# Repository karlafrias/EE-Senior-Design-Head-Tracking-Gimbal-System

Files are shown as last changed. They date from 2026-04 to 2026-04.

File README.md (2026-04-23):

# Head-Tracking FPV Camera Control System

University of North Texas  
College of Engineering  
Department of Electrical Engineering  
Senior Design  
April 2026  

## Team Members
- Karla McKenzie
- Jacob Shillingburg
- Martins Ugoh

## Advisor
- Dr. Namuduri

## Link to Youtube:
https://www.youtube.com/watch?v=_BPLgMK_N9A

This repository contains code, PCB files, 3D models, pin diagrams, datasheets, presentation materials, and documentation for our senior design project

## Repository Contents

**3D Models:** Contains 3D CAD models for the head-tracking system and related mechanical components created in Fusion 360. Also includes files used for 3D printing and system integration.

**Code:** Contains the embedded code used for the head-tracking FPV camera control system, including communication and control logic for the headset and camera system.

**Datasheets:** Contains manufacturer datasheets for key project components used in the system design and integration.

**PCB Files:** Contains the PCB design files created in Altium, along with fabrication outputs, gerber files, and other board-related design documents.

**Pin Diagrams:** Contains wiring references, pin mappings, and connection diagrams for the major components used in the project.

**Poster-Slides:** Contains our senior design poster, presentation slides, and supporting materials used to present the project.

**Technical Report:** Contains the written technical report and supporting documentation for the project.

## Project Abstract

Inspired by Max Imagination and redesigning his board, our senior design project focuses on developing a custom head-tracking FPV camera control system for real-time remote viewing applications. The goal of this project is to create a more refined and functional board that supports directional camera control through natural head movement. By redesigning the board, the team aimed to improve organization, functionality, and overall integration while supporting future use in applications such as drones, remote sensing, and first responder assistance.

Our project involved designing the PCB in Altium, developing 3D CAD models in Fusion 360, selecting and sourcing components, assembling and soldering the board, testing power and signal behavior, and integrating the board with the camera and headset system. Along the way, the team addressed engineering challenges such as axis inversion, signal routing, communication reliability, mechanical fit, and hardware integration.

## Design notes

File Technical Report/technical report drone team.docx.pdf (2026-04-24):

# Design and Integration of a Head Tracking System for Remote Camera/Gimbal Control on a UAV Drone

# EENG 4990.001 Senior Design II

# Department of Electrical Engineering

# University of North Texas

# Denton, TX, USA

# Karla McKenzie

# Martins Ugoh

# Jacob Shillingburg

04/24/2026

Page | ii
Karla McKenzie, Jacob Shilingburg, Martins Ugoh April 2026

ACKNOWLEDGMENTS

We would like to thank the College of Engineering at the University of North Texas for funding our project. We also gratefully acknowledge Dr. Namuduri and the Autonomous Systems Laboratory for their mentorship, guidance, and technical insight throughout the development process. In addition, we thank the Department of Electrical Engineering for providing advice, resources, and access to equipment and materials that made this work possible.

KEYWORDS

- camera integration
- embedded systems
- gimbal control
- head tracking
- PCB design
- remote sensing
- wearable electronics

Page | iii

CONTENTS

Abstract | 3
Introduction | 4
Solution | 6
Design | 8

Implementation 14

Conclusion | 33
Future Work | 34
References | 35
Appendix | 36

Page | iv

THIS PAGE LEFT BLANK INTENTIONALLY

Page | 5

## Abstract

The project focused on developing a dedicated hardware platform capable of receiving head -tracking input, processing motion data, and transmitting control signals to the camera gimbal for pan and tilt movement. Electrical design considerations included signal routing, power distribution, filtering components, and connector integration, while mechanical design addressed mounting, alignment, and overall system fit. Prototype development and ground-based testing were completed to evaluate communication performance and system functionality. Results showed that the system successfully demonstrated head-tracking control and reliable wireless operation at distances of up to approximately 1 km under ground test conditions. Although full flight testing was not completed, the final prototype established a strong foundation for future integration into UAV-based remote sensing platforms. This work demonstrates the feasibility of a custom head-tracking control board and supports future improvements in stabilization, durability, and full aerial deployment.

Page | 6

## Introduction

Head tracking systems are widely used in robotics, drones, teleoperation, virtual reality, and assistive systems because they provide a more natural and immersive method of control. Instead of relying entirely on joysticks or manual directional input, these systems convert the user’s head movement into corresponding control signals. This allows the operator to direct a camera or gimbal system more intuitively and efficiently.

The goal of this project was to design and integrate a head tracking system capable of supporting a remote camera or gimbal platform. The system was intended to provide real-time directional control through head movement while returning a live video feed to the user through a headset. Achieving this required reliable electronics design, stable power regulation, practical PCB layout, and careful integration with both the camera and headset hardware.

Because the system is intended for a compact and mobile environment, the design had to emphasize low power consumption, hardware reliability, compact form factor, and ease of integration. This paper discusses the design process, implementation, testing, results, and future improvements of the head tracking system.

Page | 7

## Problem Statement

Traditional remote camera control methods can be difficult to use when the operator must divide attention between navigation, observation, and directional adjustment. This is especially true in drone or remote vision applications where fast response and natural user interaction are important. A head tracking system improves usability by allowing the camera orientation to follow the operator’s head motion.

However, implementing such a system introduces several engineering challenges. The system must provide stable power delivery, reliable communication, appropriate signal conditioning, and compact physical integration. It must also account for real-world issues such as control inversion, mounting constraints, and hardware debugging. The challenge of this project was therefore to develop a PCB-based hardware platform that could support these functions while remaining compact, reliable, and suitable for integration into a headset-camera system.

## Objectives

The objectives of this project were to:

1. design a PCB for the head tracking system using Altium;
2. select and source components required for sensing, regulation, and communication;
3. develop a complete bill of materials for fabrication and assembly;
4. assemble and solder the PCB for functional verification;
5. validate power and signal behavior using laboratory test equipment;
6. integrate the board with the camera and headset system;
7. support real-time transmission and directional control capability;
8. correct control issues related to axis inversion; and
9. prepare the design for final system-level implementation.

Page | 8

## Solution

Our solution is to use a custom PCB-based head-tracking gimbal system to control an FPV camera in real time. The system allows the camera to follow the natural head movements of the user, creating a more responsive and immersive remote viewing experience. The PCB serves as the main control platform and connects the microcontroller, wireless communication modules, power components, filtering capacitors, connectors, and servo motor outputs needed for operation. The system is powered by a lithium battery pack, allowing portable use and easier integration into a mobile platform. Head-tracking input is processed and transmitted wirelessly to the receiving side, where the servo motors drive the camera in pan and tilt directions. The system also includes custom mechanical components to support the camera and gimbal assembly while keeping the design compact and adaptable. Overall, the prototype functions as a head-tracking control system for remote sensing applications and demonstrated successful operation during ground testing, with wireless performance reaching distances of up to about 1 km. Although full flight testing was not completed, the design provides a strong foundation for future improvements in stabilization, integration, and expanded field use.

Page | 9

## System Overview

The head tracking system was designed as an embedded control platform that converts user head motion into directional commands for a remote camera gimbal assembly. The system is composed of a sensing stage, a processing stage, a wireless communication stage, regulated power distribution, and a remote actuation stage. These subsystems operate together to provide real-time camera positioning and visual feedback for remote sensing applications.

The main controller used in the system is the Pro Mini ATmega328P 5V/16 MHz microcontroller, which serves as the central processing unit on the custom PCB. This microcontroller receives motion data from the inertial sensor, processes the orientation-related input, and generates the control data required for transmission to the remote platform. Its small size, low power requirements, and compatibility with the rest of the embedded design made it suitable for integration into the head-mounted control hardware.

Head motion is measured using the MPU6050 gyroscope and accelerometer sensor, which provides motion and orientation data to the microcontroller. The MPU6050 combines a 3-axis gyroscope and a 3-axis accelerometer in a single device, allowing the system to detect changes in head position and angular movement. This sensor data is used to determine the operator’s motion and convert it into corresponding control signals for the remote camera system. The sensor communicates with the microcontroller through a digital interface and forms the primary input stage of the head tracking system.

Wireless transmission between the head-mounted unit and the remote camera platform is supported through an nRF24L01 transceiver module. This communication link allows processed motion data from the headset side to be sent to the receiving side of the system, where the camera or gimbal can respond accordingly. The wireless link is intended to support low-latency transfer of directional commands, which is important for natural and responsive camera movement.

The PCB also includes the required power regulation and filtering circuitry to support stable operation of the embedded components. Decoupling and bulk capacitors were included to reduce noise and maintain voltage stability for the microcontroller, sensor, and communication module. Proper power distribution was necessary to reduce electrical instability that could affect sensing accuracy, wireless transmission, or general system reliability.

On the receiver side, control signals are used to drive the gimbal mechanism so that its motion follows the user’s head movement. This creates a closed operator feedback loop in which head orientation is measured by the MPU6050, processed by the ATmega328P, transmitted wirelessly through the nRF24L01, and then used to reposition the remote camera. A live digital camera feed is returned to the headset, allowing the operator to immediately observe the resulting view direction.

Overall, the system integrates embedded sensing, onboard signal processing, wireless communication, and remote actuation into a compact hardware platform. This architecture supports intuitive camera control for drone-based remote sensing and first responder applications.

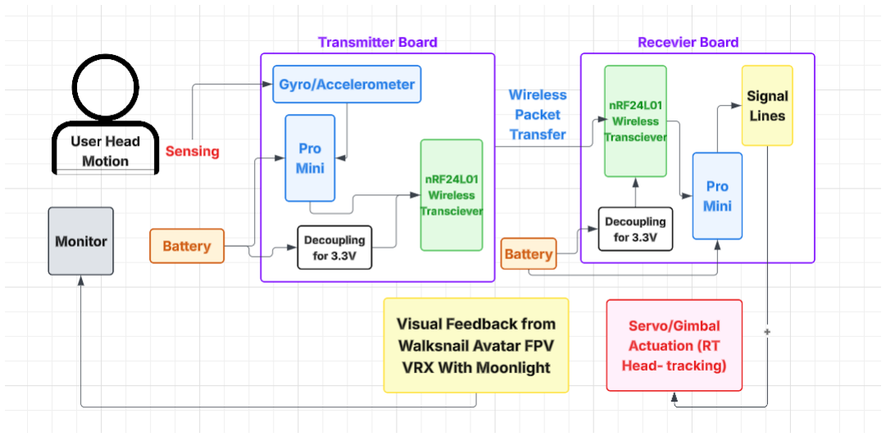
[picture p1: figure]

Page | 10

## Design

## Design Overview

Figure 1: PCB Carrier Board Overview Block Diagram

System-level block diagram of the head tracking platform showing the user input, transmitter board, wireless packet-based communication link, receiver board, and visual feedback path. On the transmitter side, head motion is measured by the gyro/accelerometer and processed by the Pro Mini before being sent through the nRF24L01 wireless transceiver. The receiver board accepts the transmitted packets and outputs the control signals used for servo or gimbal actuation. The diagram also shows the battery-powered supply and decoupling required for stable 3.3 V operation, as well as the returned visual feedback from the FPV system to the user monitor.

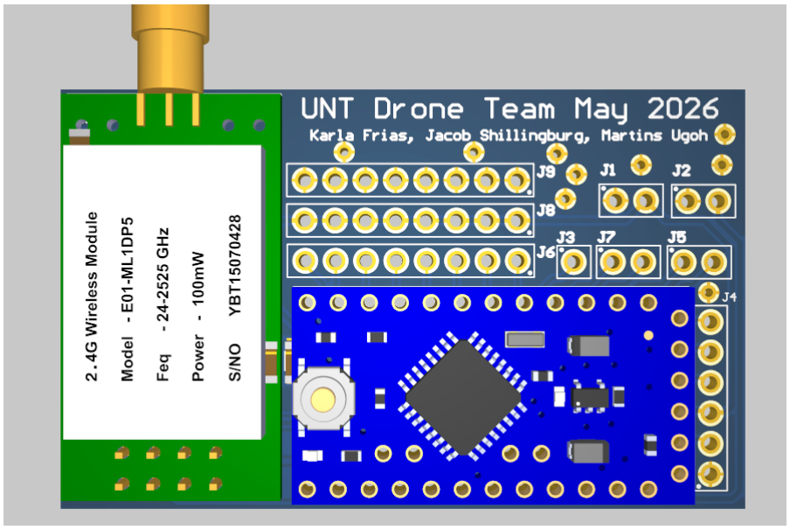
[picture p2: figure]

Page | 11

## Electrical Design

The electrical design focused on creating a reliable PCB capable of distributing power and supporting required interfaces for the head tracking system. Schematic capture was completed in Altium with attention given to connector placement, routing simplicity, electrical stability, and compact form factor. Proper filtering and decoupling were included to minimize noise and maintain stable supply rails.

Power integrity was an important consideration because instability in the supply could reduce sensing accuracy, affect communication performance, or create unreliable system behavior. Capacitor placement near active components and appropriate routing practices were therefore incorporated into the design.

Figure 2: 3D PCB Carrier Board (Front)

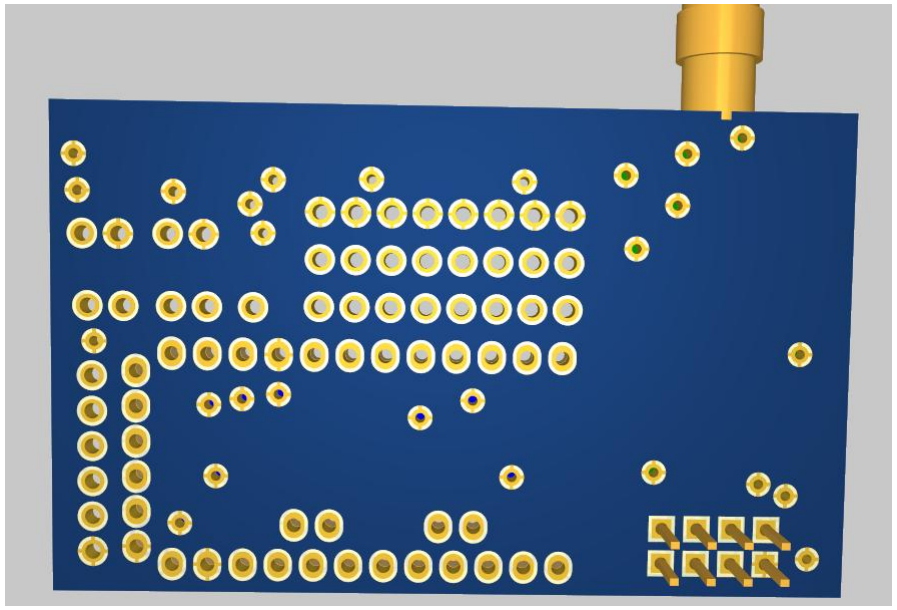
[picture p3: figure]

Page | 12

Figure 3: 3D PCB Carrier Board (Back)

The head tracking system was implemented on a two-layer printed circuit board designed in Altium Designer. After the schematic was completed, the components were assigned footprints and transferred into the PCB layout environment. The board was arranged to support the Pro Mini ATmega328P 5V/16 MHz, MPU6050 gyro/accelerometer, nRF24L01, and the required power regulation circuit in a compact carrier-board suitable for integration with the system.

The power section was designed around an AMS1117-3.3 voltage regulator to provide a stable 3.3 V supply. To support regulator stability and reduce electrical noise, the design used a combination of bulk and ceramic capacitors. C1 was 22 uF at the regulator input, and C5 was 10 uF at the regulator output for bulk filtering. The remaining capacitors, C2, C3, C4, C6, C7, and C8, were 0.1 uF, and were used for high-frequency decoupling and local noise suppression. This filtering approach helped improve voltage stability and support reliable operation of the embedded components.

Once the schematic and layout were finalized, routing was completed. Special attention was given to the placement of the voltage regulator, decoupling capacitors, and communication-related components so that power and signal paths could be kept as short and practical as possible. Design rule checks were then performed in Altium to verify spacing, connectivity, and board manufacturability before generating the final fabrication files. After fabrication, the board was soldered as part of the hardware implementation process. This included mounting the required passive and active components and preparing the board for electrical validation and integration

Page | 13

with the system. Following assembly, the board could then be used for validation of power delivery, signal behavior, and system integration with the camera and headset setup.

## Component Selection

Component selection was based on electrical compatibility, compact integration, availability, and suitability for prototype testing. A major goal of the design was to use easily procurable parts, including components that could be sourced quickly from vendors on Amazon, so that assembly and testing could proceed without long procurement delays. This made the design more practical for rapid prototyping and reduced the risk of project delays caused by limited part availability.

The primary controller selected for the design was the Pro Mini ATmega328P 5V/16 MHz. This microcontroller was chosen because of its compact size, straightforward integration, and ability to interface with both the sensing and wireless communication hardware. It served as the main processing element of the transmitter board and handled the motion data used for head tracking control. The MPU6050 gyroscope and accelerometer was selected as the motion-sensing device. In this design, the MPU6050 was mounted directly on top of the Pro Mini, which meant it did not require additional PCB area on the carrier board. This arrangement helped reduce the effective space required by the sensing hardware and supported a more compact overall design. The sensor provided the motion information needed to determine the user’s head orientation. Wireless communication was implemented using an nRF24L01 transceiver module. It was selected because it supports packet-based communication and is widely used in embedded control systems. The processed motion information was divided into two control components, pitch and yaw, before transmission. On the receiving side, these two data components were read and used by the servo system to drive gimbal pan and tilt motion. This allowed the head tracking system to convert user motion into separate directional control signals for remote actuation. Power regulation was supported using the AMS1117-3.3 voltage regulator, which provided the required 3.3 V supply for devices operating below the main input voltage. Capacitors were selected to support both regulator stability and noise filtering. Bulk capacitors were used to help smooth supply variations, while smaller ceramic capacitors were used for high-frequency decoupling. This combination provided a practical and effective filtering method for stable board operation.

In addition to the control electronics, extra design consideration was given to the return video system. More money was intentionally spent to obtain a digital video feed for the return path so the system could be tested more effectively at longer distances. This decision improved the ability to evaluate the platform under more realistic remote-operation conditions and supported clearer visual feedback during testing.

Overall, the selected components provided a practical balance of performance, compactness, cost, and availability. The use of readily available parts, compact sensor mounting, packet-based pitch and yaw transmission, and an upgraded digital return video system supported the development of a workable prototype for head tracking and remote camera control for first responders.

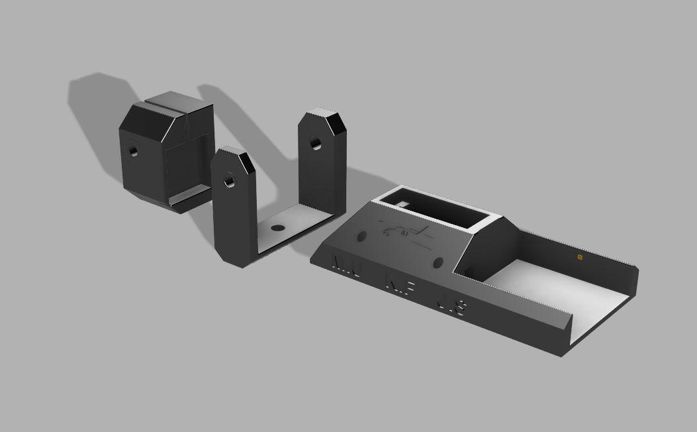
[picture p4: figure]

Page | 14

### Mechanical Integration

Mechanical integration involved combining the electronics with the camera and headset structure. The design included the use of screws, M3 bolts, threads, and supporting mechanical features to secure the electronics and associated camera components in the final assembly. Mechanical constraints influenced the PCB dimensions, connector orientation, and overall system packaging.

This stage emphasized that successful embedded design requires coordination between electrical and mechanical considerations rather than treating them as separate tasks.

Figure 4: 3D Gimbal System Design

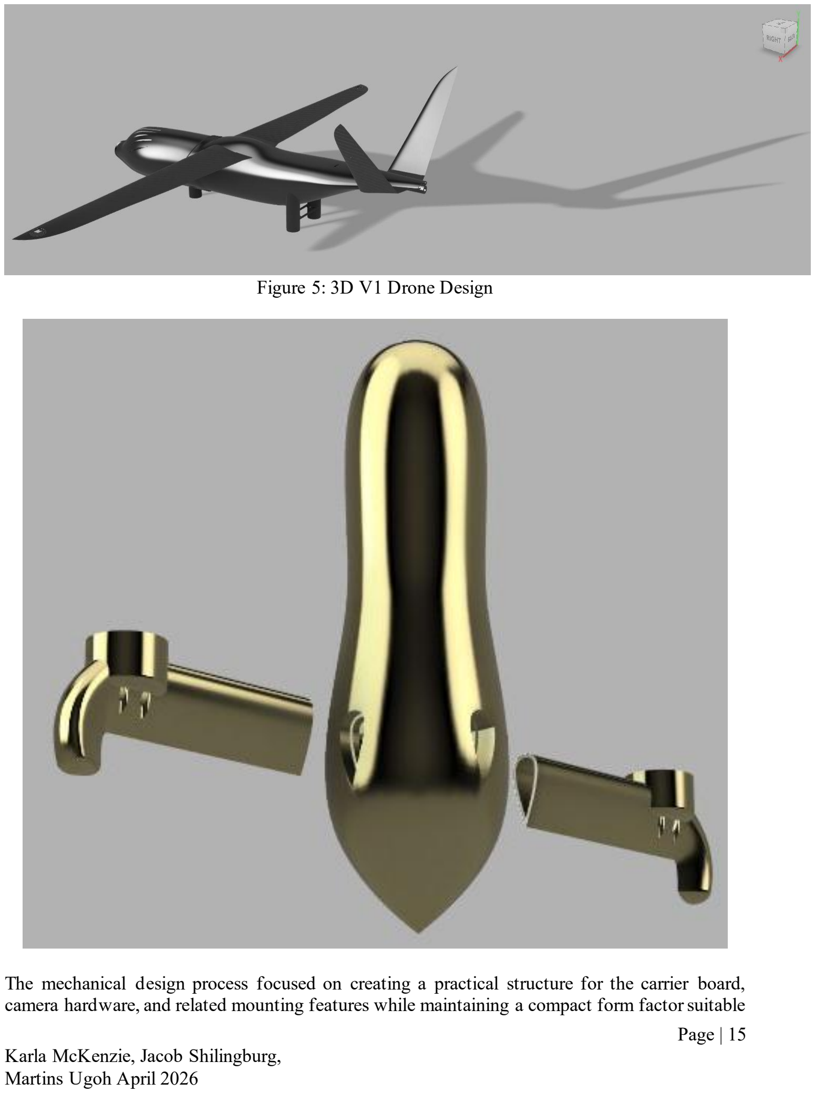
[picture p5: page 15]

Page | 15

Figure 5: 3D V1 Drone Design

The mechanical design process focused on creating a practical structure for the carrier board, camera hardware, and related mounting features while maintaining a compact form factor suitable

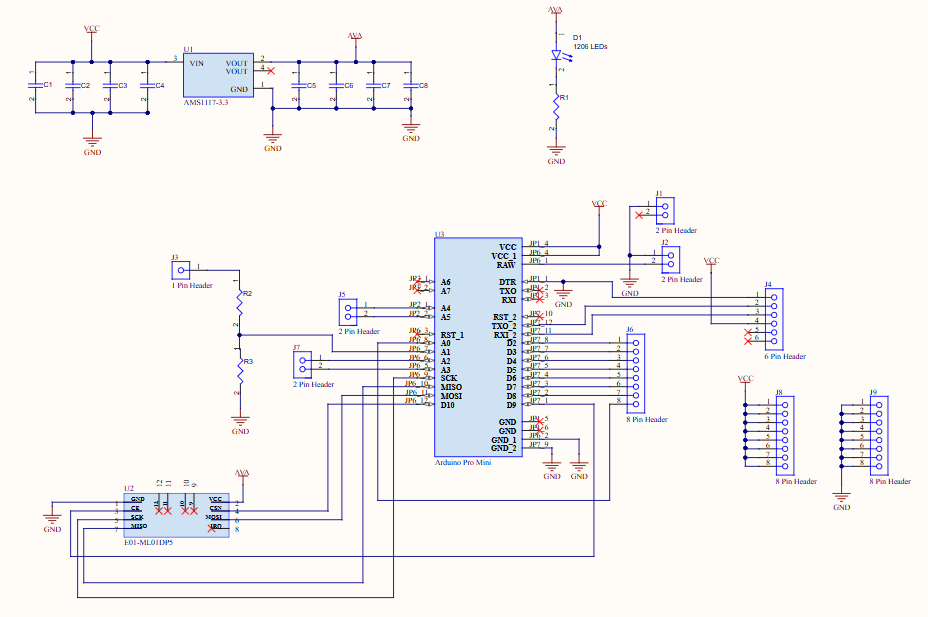
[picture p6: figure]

Page | 16

for the intended drone platform. In addition to the head tracking hardware assembly, two drone configurations were also designed for test flights to evaluate system integration. Using Fusion 360, the mechanical components were modeled to support placement of the PCB, camera, and structural hardware within the available space.

The design also considered fastening and assembly requirements, including the use of screws, mounting holes, and support features needed to secure the board and camera components during testing and operation. Proper mechanical support was especially important because the system is intended for a moving platform, where vibration and repeated handling can affect reliability. By developing the structure in CAD before fabrication, the design process improved the likelihood of successful assembly and helped reduce integration issues during testing.

## Implementation

### Schematic and PCB Development

The implementation began with schematic development and PCB design in Altium. After the circuit was completed and checked, a bill of materials was prepared to support part procurement. Once components were obtained, the board was soldered and assembled.

Figure 6: Altium Schematic for PCB Carrier Board

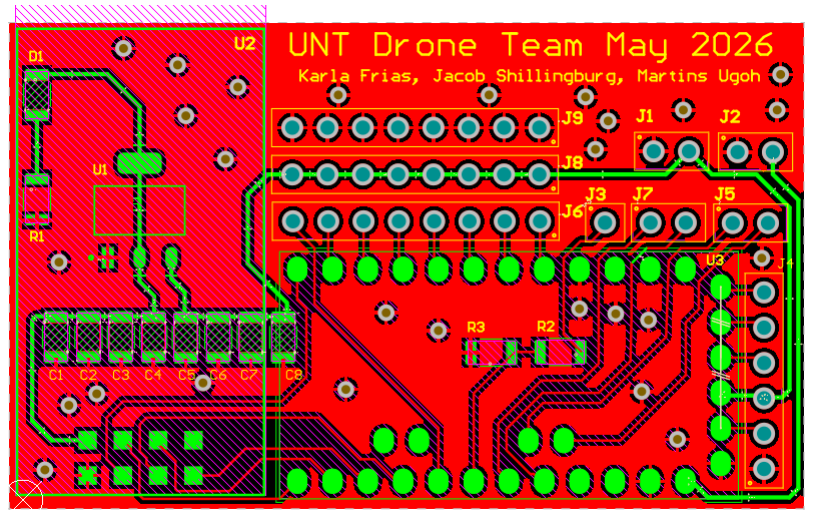
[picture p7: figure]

Page | 17

Figure 7: Altium Top Layer (GND and Signals) for PCB Carrier Board

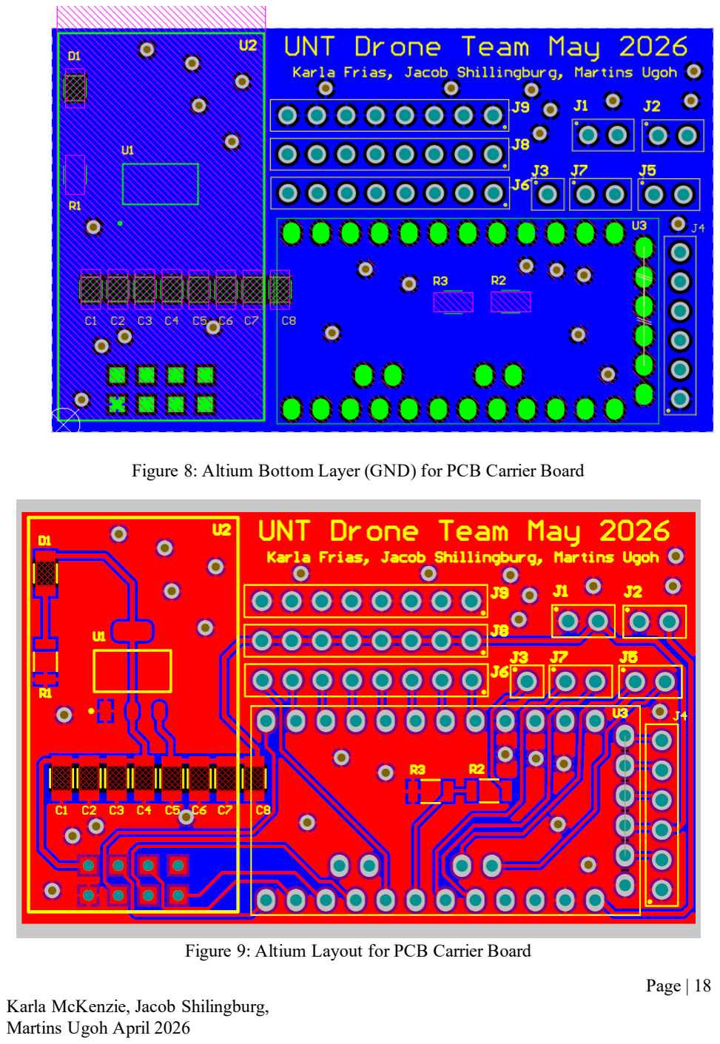
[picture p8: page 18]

Page | 18

Figure 8: Altium Bottom Layer (GND) for PCB Carrier Board

Figure 9: Altium Layout for PCB Carrier Board

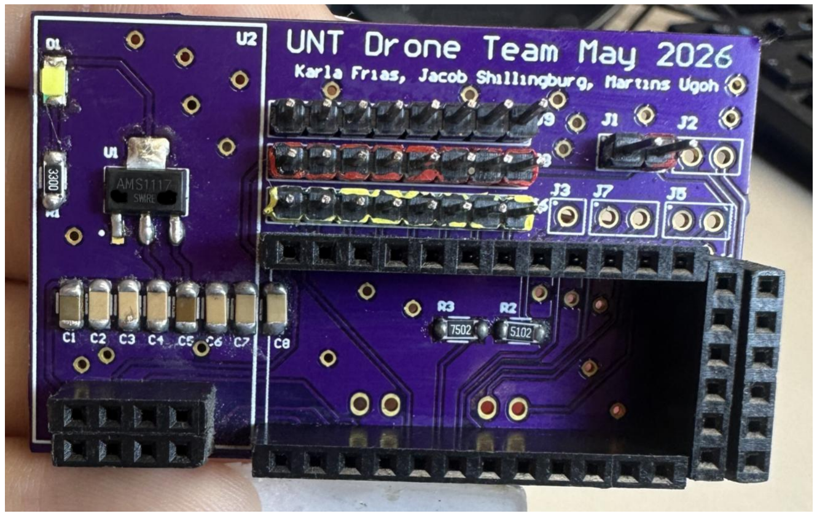
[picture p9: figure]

Page | 19

### Board Assembly

After fabrication, the PCB was assembled and soldered. During assembly, component placement and solder joints were checked carefully to reduce the risk of shorts, poor connections, or incorrect orientation. A high-quality assembly process was important because later debugging becomes significantly more difficult when hardware faults are introduced at this stage.

Figure 10: Assembled PCB Carrier Board (Front)

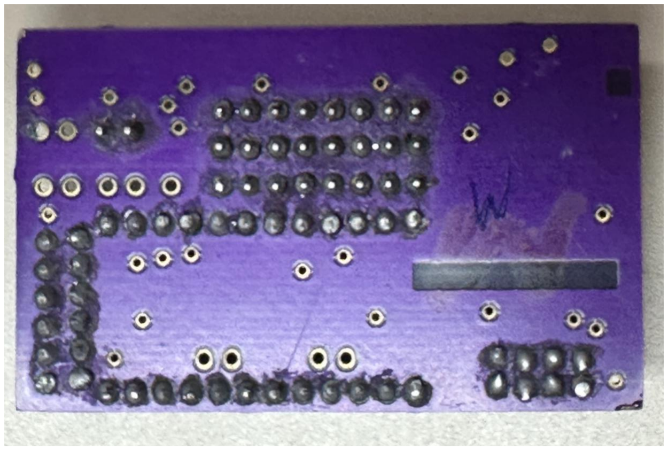
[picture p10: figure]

Page | 20

Figure 11: Assembled PCB Carrier Board (Back)

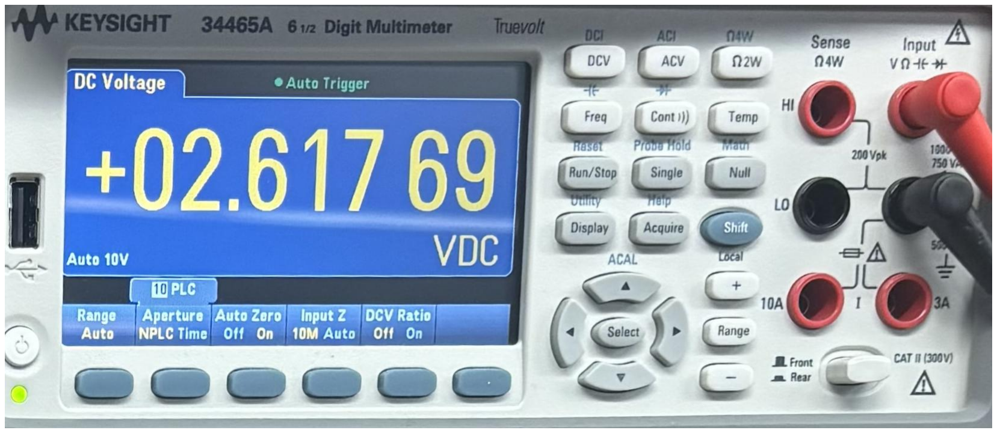
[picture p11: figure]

Page | 21

### Hardware Validation

Following assembly, the board was validated in the laboratory using oscilloscopes and standard test equipment. These tests focused on verifying power rails, signal continuity, and basic board functionality before attempting full system integration.

Initial testing showed that the board provided the required electrical support for continued development. Stable power delivery and functional interface behavior allowed integration efforts to proceed with confidence that the hardware foundation was operating properly.

Figure 12: Digital Multimeter LED and nRF24 Module Voltage

Board VCC | LED Voltage | Active Current (mA)
Idle | Current
| | | (mA)
5.0 | 3.265 | 5.26 | 2.21
4.8 | 3.152 | 4.99 | 2.19
4.6V | 3.054 | 4.68 | 2.14
4.4V | 2.976 | 4.32 | 2.10
4.2V | 2.853 | 4.08 | 2.04
4V | 2.617 | 4.19 | 2.01
3.8V | 2.502 | 3.93 | 1.98
3.6V | 2.448 | 3.49 | 1.94
3.4 | 2.434 | 2.93 | 1.92

Page | 22

### Transmitter Code

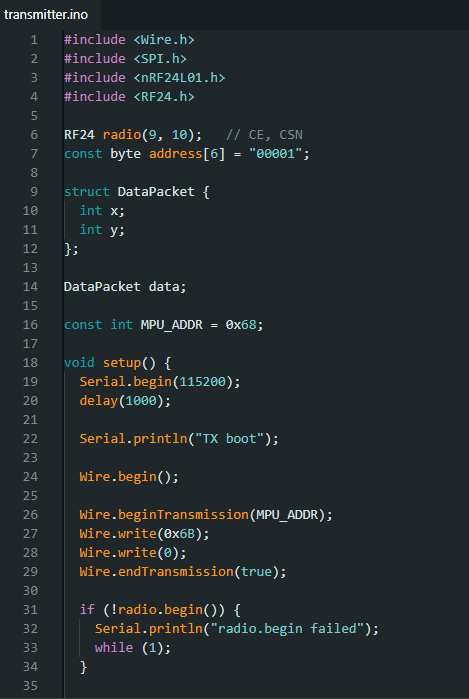
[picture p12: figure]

Page | 23

Figure 13: Transmitter C++ Code

Page | 24

### Receiver Code

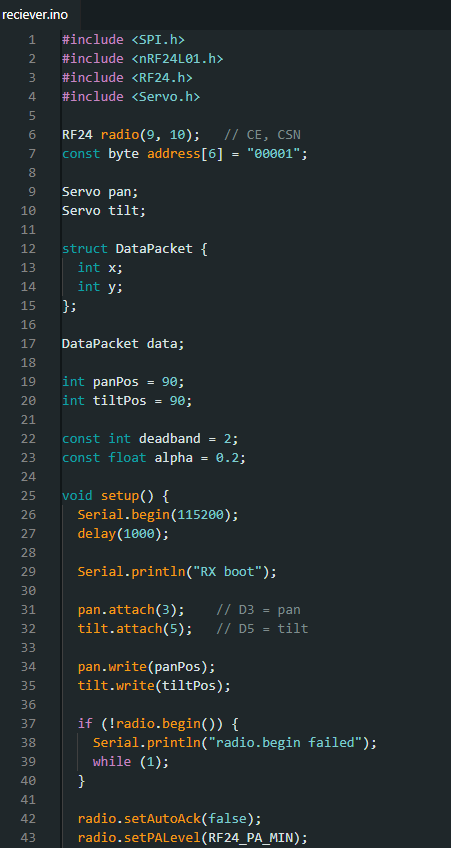
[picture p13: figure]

Page | 25

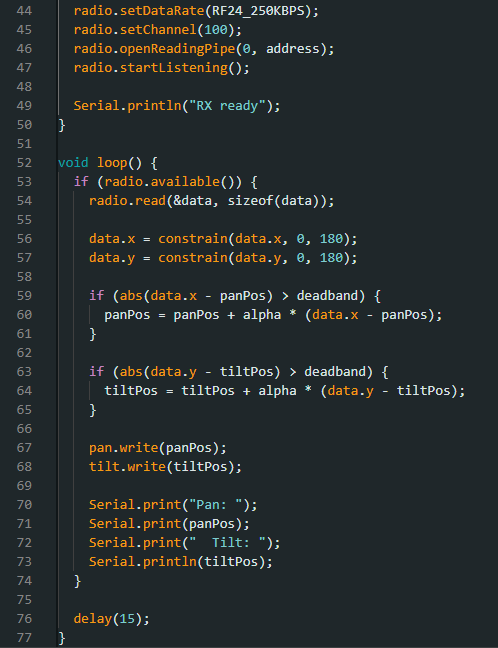
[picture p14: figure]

Figure 14: Receiver C++ Code

Page | 26

### System Integration

System integration involved combining the electrical, mechanical, communication, and video subsystems into one functional head tracking platform. After the carrier board was designed, fabricated, and soldered, it was connected with the motion sensor, wireless modules, servo system, camera hardware, and video components to verify complete system operation. This stage was necessary to confirm that the individual subsystems could work together as a single embedded control system.

On the transmitter side, the MPU6050 provided motion data to the Pro Mini ATmega328P 5V/16 MHz, where the input was processed into pitch and yaw values. These two control components were then organized into packets and transmitted through the nRF24L01 wireless communication link. On the receiving side, the transmitted data was read and used to control the servo motors responsible for gimbal pan and tilt motion. This confirmed that the sensing, processing, and wireless control chain could be successfully integrated across both sides of the system.

System integration also included the return video path. A digital video feed was selected for the feedback system to support clearer viewing and better testing at longer distances. This allowed live camera output to be returned to the user display, completing the operator feedback loop and making it possible to observe the effect of head movement on remote camera direction in real time.

Mechanical integration was also an important part of this process. The board, camera hardware, and mounting structure were designed in Fusion 360 and assembled using the required support features, mounting holes, and fasteners. This helped ensure that the electronics could be physically secured within the platform and remain stable during handling and testing. Together, these steps demonstrated that the head tracking system could function as a complete integrated prototype and provided a foundation for continued refinement toward smoother control response and future drone-based deployment.

## Testing and Results

Testing of the complete head tracking system was performed in stages to verify electrical operation, wireless communication, mechanical integration, and overall system functionality. The

Page | 27

purpose of testing was to confirm that the transmitter board, receiver board, and camera feedback system could operate together as an integrated platform for remote camera control.

Initial testing focused on power regulation and board-level operation. The custom carrier board was powered and checked to verify that the regulator stage provided the required supply levels for the onboard electronics. Voltage measurements and current testing were used to confirm stable operation across the expected input range. The board remained functional as the supply was varied, and current measurements were recorded for both idle and active conditions. These tests helped verify that the PCB could reliably support the microcontroller, sensor, and wireless transceiver.

Additional testing was then performed on the sensing and control path. The MPU6050 sensor successfully provided motion-related input to the Pro Mini ATmega328P, allowing head motion data to be processed and separated into pitch and yaw control components. These two data values were then organized for packet-based transmission through the nRF24L01 wireless link. On the receiving side, the transmitted data was read and used to drive the servo system. This confirmed that the end-to-end control path, from sensed head motion to servo output, was functioning as intended.

System testing also showed that the head tracking direction was operating correctly and no longer required axis inversion. However, the motion response can still be improved to make the tracking smoother. Although the system followed the expected directional behavior, further tuning would help reduce abrupt motion and produce more natural camera movement.

The return video path was also tested as part of the full system evaluation. A digital video feed was selected for the return path in order to support testing at longer distances and provide clearer visual feedback during operation. This allowed the camera output to be viewed more effectively during system testing and confirmed that the visual feedback path was functional. Establishing a working return video link was an important result because it demonstrated that the operator could receive real-time visual information while using the head tracking system.

Mechanical integration was evaluated through physical assembly and fit testing of the carrier board, camera hardware, and mounting structure. CAD models developed in Fusion 360 supported the placement of these components before fabrication, and the assembled hardware confirmed that the board and related components could be mounted within the intended platform. Fastening methods, alignment, and structural support were reviewed during assembly to confirm that the hardware could remain secured during handling and testing.

Testing of the larger platform identified system-level limitations as well. While the PCB itself was compact and lightweight enough for integration, one of the heavier drone configurations limited the ability to perform multiple full test flights. As a result, complete flight-based validation of the entire system was restricted. Even so, subsystem testing confirmed that the electronics, communication link, servo output, and video return path were operating and ready for further refinement.

Overall, the testing results demonstrated that the project successfully produced a functional prototype head tracking system. The PCB operated correctly, packet-based wireless communication was established, servo control based on pitch and yaw data was demonstrated, and

Page | 28

the digital return video path was successfully connected. These results show that the system provides a solid foundation for continued development toward smoother tracking performance, stronger connector reliability, environmental protection, and future drone or first responder deployment.

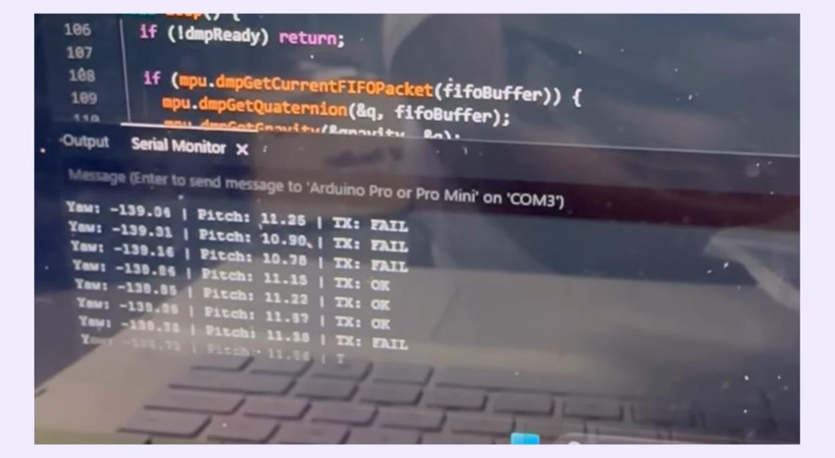
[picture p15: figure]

Figure 15: Serial Monitor Output During Testing (test 1)

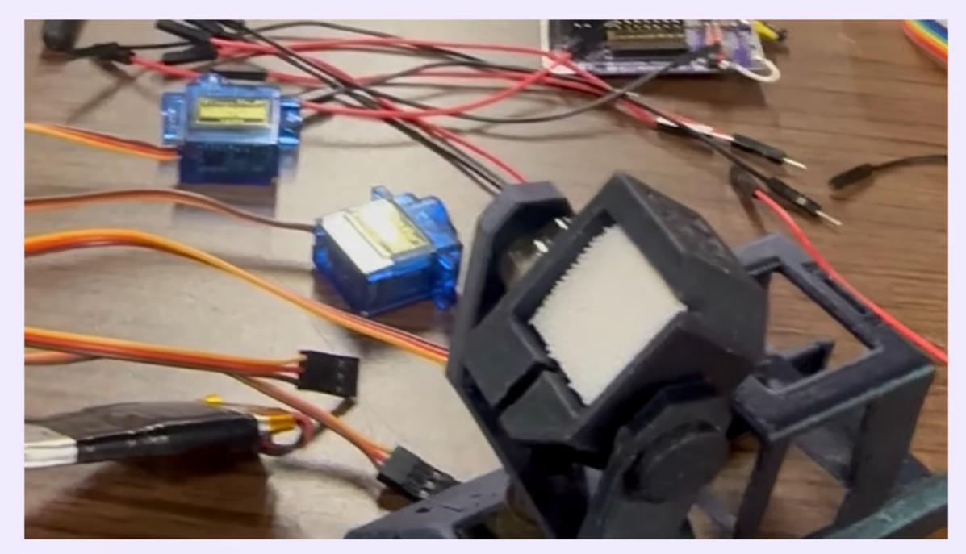
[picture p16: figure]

Figure 16: Pan/Tilt Output During Testing (test 1)

Page | 29

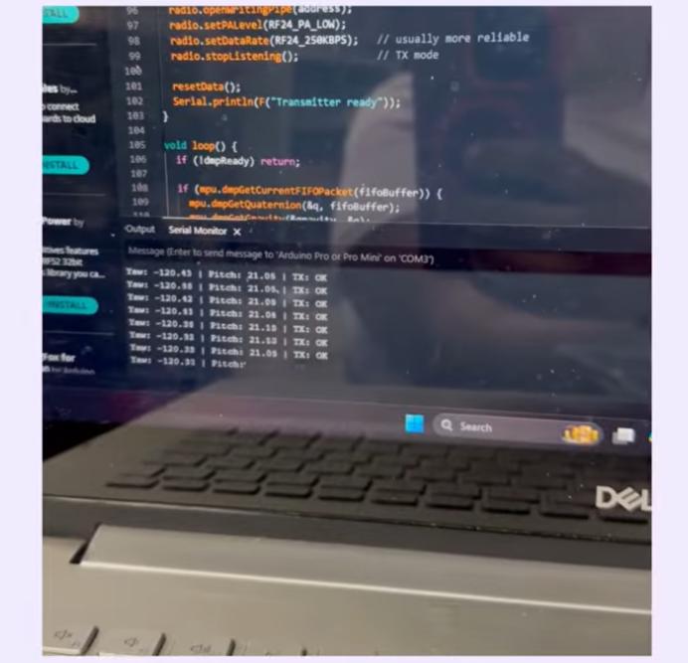
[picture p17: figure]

Figure 17: Serial Monitor Output During Testing (test 2)

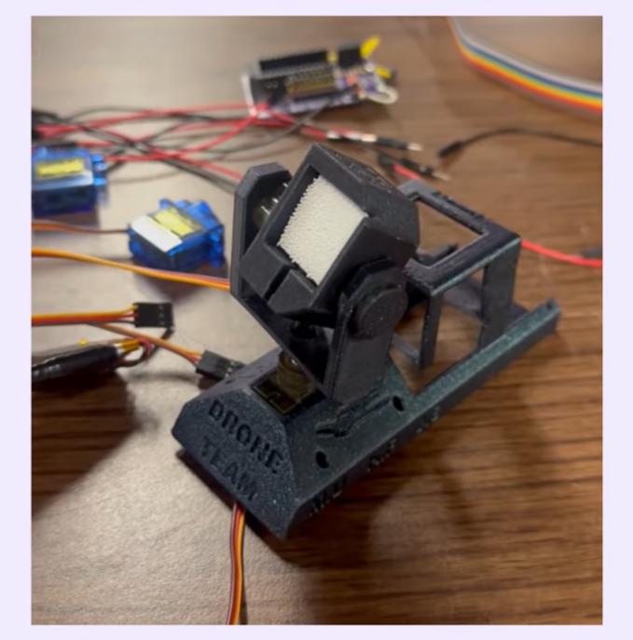
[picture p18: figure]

Figure 18: Pan/Tilt Output During Testing (test 2)

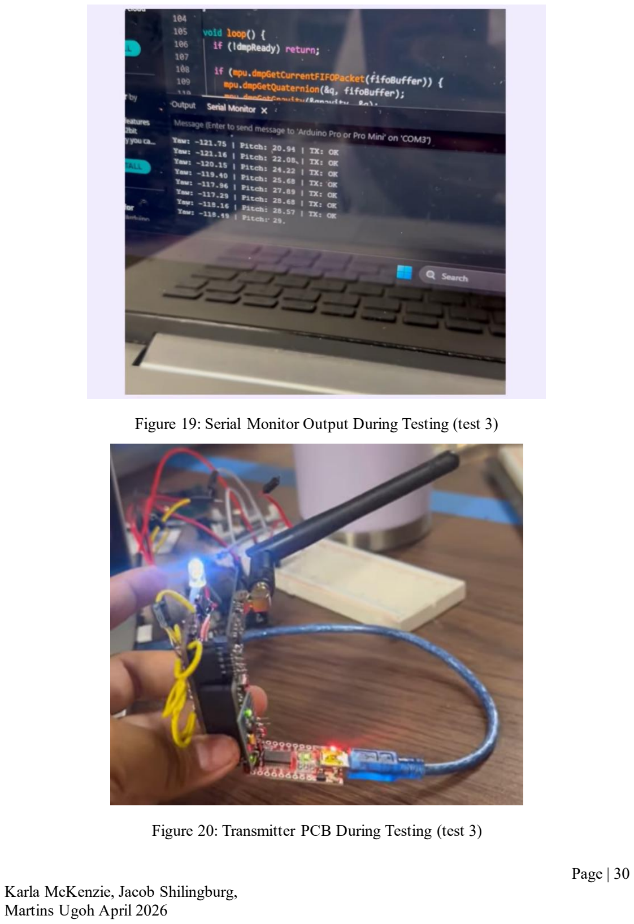
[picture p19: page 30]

Page | 30

Figure 19: Serial Monitor Output During Testing (test 3)

Figure 20: Transmitter PCB During Testing (test 3)

Page | 31

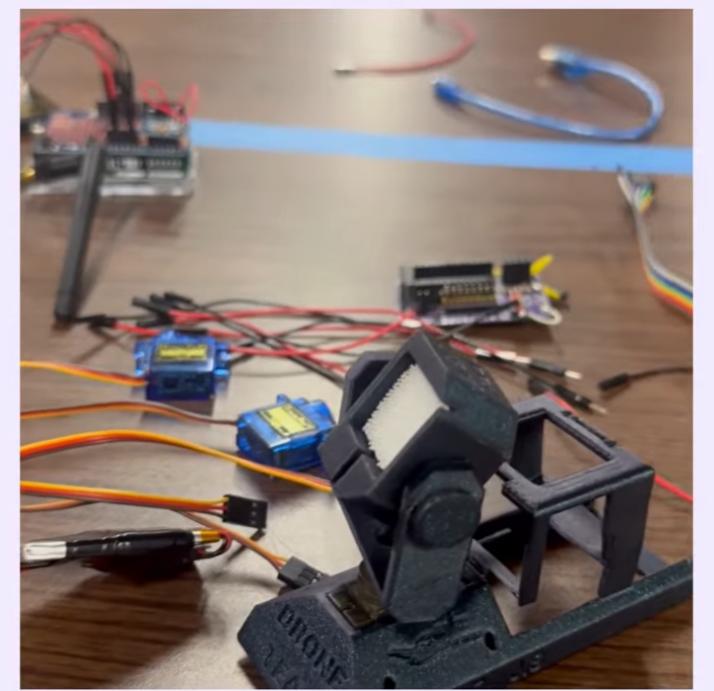
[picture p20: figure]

Figure 21: Pan/Tilt Output During Testing (test 3)

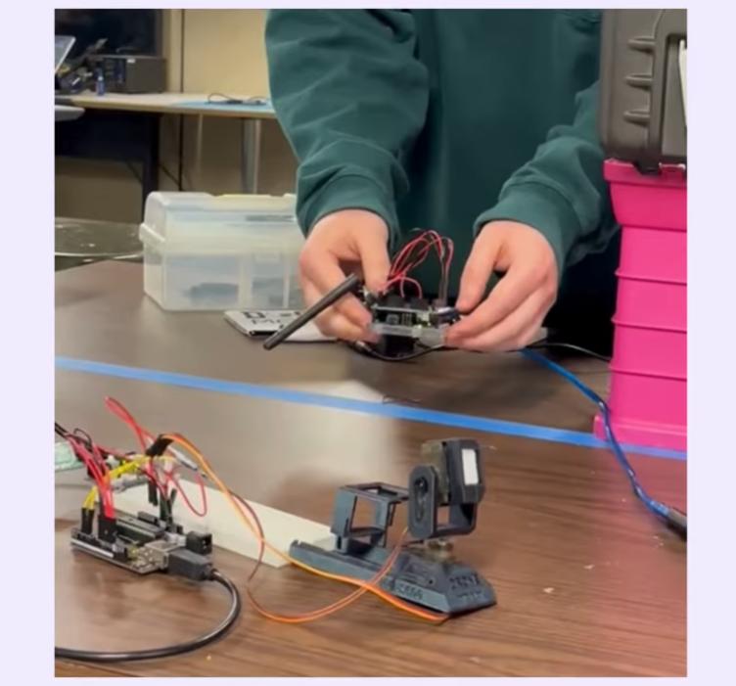
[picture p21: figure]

Figure 22: Pan/Tilt Output During Testing entire system (test 4)

Page | 32

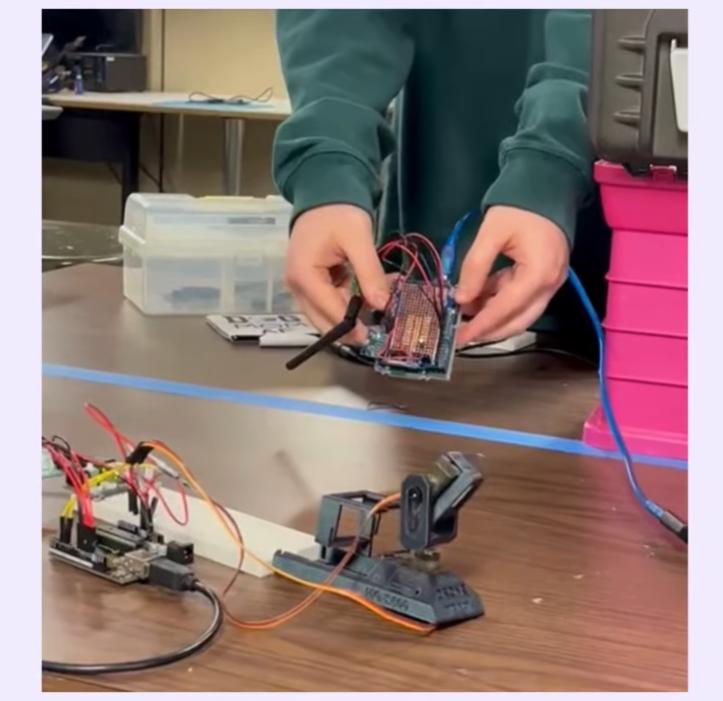
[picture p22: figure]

Figure 23: Pan/Tilt Output During Testing Entire System (test 5)

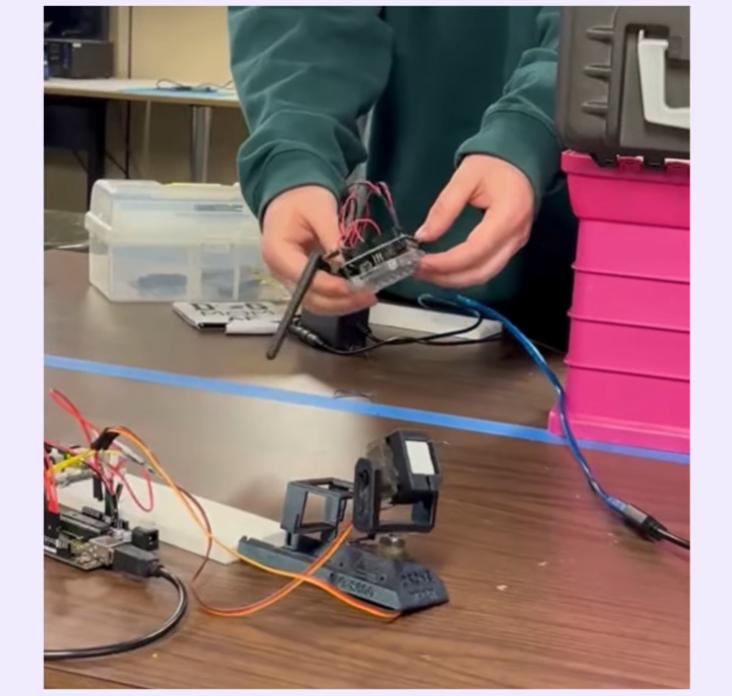
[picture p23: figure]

Figure 24: Pan/Tilt Output During Testing Entire System (test 6)

Page | 33

## Challenges and Discussion

Several challenges were encountered during the design, assembly, and integration of the head tracking system. One challenge was related to the overall drone platform used during development. While the PCB itself was lightweight and suitable for integration, the heavier drone design limited the ability to perform multiple test flights. This reduced opportunities for full flight-based validation and made it more difficult to evaluate the system under repeated real operating conditions.

Another challenge involved achieving smooth and stable camera response from the head tracking input. Although the system functioned correctly and the tracking direction no longer required axis inversion, the motion response can still be improved to provide smoother operation. This highlighted the importance of control tuning and system refinement in addition to basic hardware functionality.

A further challenge involved the physical connections used on the board. The current pin headers allowed the system to be assembled and tested, but they are not ideal for repeated use or long-term deployment because they can become loose or stripped. This created concerns about reliability during testing and future drone integration. As a result, connector durability became an important design consideration beyond the initial electrical functionality.

System-level factors such as platform limitations, electrical design, mechanical integration, connector reliability, and environmental protection all contribute to final performance. The work completed in this project established a functional prototype and also revealed the practical improvements needed to make the system smoother, more durable, and better suited for real-world drone and first responder deployment.

Page | 34

## Conclusion

The head tracking system developed in this project successfully demonstrated the design and integration of a custom PCB for remote camera control applications. The project included schematic capture, PCB layout in Altium, component selection, bill of materials development, soldering, hardware validation, and integration with the camera and headset system. A clear digital camera feed was successfully connected to the headset, confirming that the system established a functional visual link and a solid foundation for directional camera control.

The final prototype showed that the head tracking system operates correctly and no longer requires axis inversion, although additional refinement is still needed to make the motion response smoother. The project also identified practical improvements for long-term reliability, including replacing the current pin headers with more secure connectors and applying conformal coating to protect the board in drone-based environments.

Overall, this work demonstrated the feasibility of a compact, PCB-based head tracking platform for remote sensing and camera positioning. With continued refinement, the system can support more reliable operation in drone and first responder applications, where intuitive control, stable visual feedback, and durable hardware are especially important.

Page | 35

## Future Work

Future work will focus on improving the overall performance, durability, and field readiness of the head tracking system. Although the PCB was successfully designed, assembled, and integrated with the camera display, additional refinement is still needed to improve the smoothness of the head tracking response. The current system functions as intended, but further tuning of the control behavior would help produce more stable and natural camera motion during operation.

Future development should focus on optimizing responsiveness and reducing any jitter or abrupt movement in the control output. This would improve user experience and make the system more suitable for practical remote viewing applications.

Another important area for future work is the replacement of the current pin headers with a more secure connection method. The existing pin headers can be easily stripped or loosened during repeated use, which may reduce reliability during testing and deployment. Replacing them with a stronger and more durable connector solution would improve the robustness of the system and support long-term integration.

Because the system is intended for use on a drone platform, future work should also include applying conformal coating to the PCB. Conformal coating would help protect the electronics from moisture, dust, contamination, and other environmental conditions encountered during flight operations. This added protection would improve reliability and make the board more suitable for outdoor and field deployment.

These improvements would support the development of a more reliable system for first responder applications, where stable remote vision, durability, and rapid situational awareness are especially important. With additional refinement, the system could provide a stronger platform for drone-based camera control in emergency response and other field environments.

Page | 36

## References

[1] Max Imagination, “Build an Arduino FPV Head Tracking Camera for RC Vehicles,” YouTube, video. [Online]. Available: https://www.youtube.com/watch?v=Tu0cay6S5WI.
[2] | Altium, | “Altium | Education | Programs,” | Altium. | [Online]. | Available:
https://www.altium.com/education
[3] | Autodesk, | “Fusion,” | Autodesk. | [Online]. | Available:
https://www.autodesk.com/products/fusion-360.
[4] | Arduino, | “Nano,” | Arduino | Documentation. | [Online]. | Available:
https://docs.arduino.cc/hardware/nano.
[5] Arduino, “Arduino Nano Datasheet,” Arduino Documentation. [Online]. Available: https://docs.arduino.cc/resources/datasheets/A000005-datasheet.pdf.
[6] Chengdu Ebyte Electronic Technology Co., Ltd., “E01-ML01DP5,” EBYTE. [Online]. Available: https://www.cdebyte.com/products/E01-ML01DP5.
[7] Chengdu Ebyte Electronic Technology Co., Ltd., “E01-ML01DP5 User Manual,” EBYTE. [Online]. Available: https://www.cdebyte.com/pdf-down.aspx?id=1552. Accessed: Apr. 23, 2026.
[8] TMRh20, “RF24 Documentation,” RF24. [Online]. Available: https://tmrh20.github.io/. Accessed: Apr. 23, 2026.
[9] | nRF24, | “RF24,” | GitHub | repository. | [Online]. | Available:
https://github.com/nRF24/RF24/tree/master. Accessed: Apr. 23, 2026.
[12] J. Rowberg, “Arduino/MPU6050,” in i2cdevlib, GitHub repository. [Online]. Available: https://github.com/jrowberg/i2cdevlib/tree/master/Arduino/MPU6050. Accessed: Apr. 23, 2026.
[13] All Datasheet, “AMS1117-3.3,” low-dropout voltage regulator datasheet. [Online]. Available: https://www.alldatasheet.com/datasheet-pdf/pdf/49118/ADMOS/AMS1117.html.
[14] | Tower | Pro, | “MG90S,” | Tower | Pro. | [Online]. | Available:
https://towerpro.com.tw/product/mg90s-3/.
[15] CADDXFPV, “Walksnail Avatar HD System, FPV VRX With Moonlight Kit” Manual downloads. [Online]. Available: https://www.caddxfpv.com/pages/download-center.

Page | 37

## Appendix

## Appendix A: 3D Model Files

https://github.com/karlafrias/EE-Senior-Design-Head-Tracking-Gimbal-System/tree/main/3D%20Models

## Appendix B: PCB Files

https://github.com/karlafrias/EE-Senior-Design-Head-Tracking-Gimbal-System/tree/main/PCB%20Files

## Appendix C: PCB Component List

Transmitter/Receiver PCB Parts List

Label | Description | Value | Package | Required?(no= optional)
D1 | LED White | n/a | 1206 SMD | Yes
R1 | 1/8W 1% Resistor | 330 Ω | 1206 SMD | Yes
U1 | AMS1117 – 3.3V | n/a | SOT-223 | Yes
C1 | Bulk Decoupling Voltage Regulator Capacitor | 22uF | 1206 SMD | Yes
C2 | Decoupling Voltage Regulator Capacitor | .1uF | 1206 SMD | Yes
C3 | Decoupling Voltage Regulator Capacitor | .1uF | 1206 SMD | No
C4 | Decoupling Voltage Regulator Capacitor | .1uF | 1206 SMD | No
C5 | Bulk Decoupling Voltage Regulator Capacitor | 10uF | 1206 SMD | Yes
C6 | Decoupling Voltage Regulator Capacitor | .1uF | 1206 SMD | Yes
C7 | Decoupling Voltage Regulator Capacitor | .1uF | 1206 SMD | No
C8 | Decoupling Voltage Regulator Capacitor | .1uF | 1206 SMD | No
U2 | E01-ML01DP5 Wireless Transmission Module | n/a | n/a | Yes
R2 | 1/8W 1% Resistor | 51 Ω | 1206 SMD | No

Page | 38
R3 | 1/8W 1% Resistor | 75 Ω | 1206 SMD | No
U3 | Pro Mini Atmega328P 5V/16MHz | n/a | n/a | Yes
J1 | 2.54MM Male Header (VCC) | n/a | 2 pin | Yes
J2 | 2.54MM Male Header | n/a | 2 pin | No
J3 | 2.54MM Male Header | n/a | 1 pin | No
J4 | 2.54MM Female Header | n/a | 6 pin | Yes
J5 | 2.54MM Male Header | n/a | 2 pin | No
J6 | 2.54MM Male Header (Signal Rail) | n/a | 8 pin | Yes
J7 | 2.54MM Male Header | n/a | 2 pin | No
J8 | 2.54MM Male Header (5V Rail) | n/a | 8 pin | Yes
J9 | 2.54MM Male Header (Ground) | n/a | 8 pin | Yes

Table : Transmitter/Receiver Component List

Transmitter PCB Parts List

Label | Description | Placement | Required?
n/a | MPU6050 Accelerometer/Gyroscope Sensor | Attaches to Arduino | Yes

Table : Transmitter Component List

## Appendix D: System Component List

System Parts List

Name | Description | Required?
Walksnail Avatar FPV VRX With Moonlight Kit | FPV camera kit for drone use | Yes
Walksnail Avatar HD Goggles L | Digital headset | Yes
FEELWORLD P6XL 6 inch | Monitor | Yes
18650 3000mAh Battery Cell | Receiver board battery | Yes

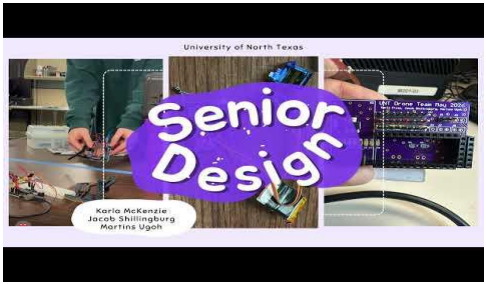
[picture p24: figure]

Page | 39
3.7V LiPo Battery 500mAh | Transmitter board battery | Yes
5V 1A Boost Power Supply Module | Use in parralel with battery packs for charging and 5V boost for PCB board | Yes

Table : System Component List

## Appendix E: Transmitter/Receiver Code

https://github.com/karlafrias/EE-Senior-Design-Head-Tracking-Gimbal-System/tree/main/Code

## Appendix F: Component Data Sheets

https://github.com/karlafrias/EE-Senior-Design-Head-Tracking-Gimbal-System/tree/main/Datasheets

## Appendix G: YouTube Video

https://www.youtube.com/watch?v=_BPLgMK_N9A

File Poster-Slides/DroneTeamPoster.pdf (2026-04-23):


[1] MPU-6050, “Accelerometer/Gyroscope Sensor Module,” documentation.
[2] AMS1117, “LDO Voltage Regulator,” datasheet.
[3] WTO5 FPV camera, product documentation.
[4] MG90S micro servo motor, product documentation.
[5] E01-ML01DP5 transceiver module, documentation.


This project presents the design and development of a head-tracking FPV camera control system for remote sensing application. The system allows an FPV camera to follow a user’s head movements in real time, improving situational awareness and control for remotely operated platforms such as drones. The design integrates embedded control, wireless communication, servo actuation, and a custom PCB to create a compact and functional prototype. This work demonstrates the potential of head-tracking technology to support applications such as first responder assistance, surveillance, and remote navigation.

In critical remote operations, every second and every viewing angle matters. Traditional FPV camera systems are limited because they often force the operator to rely on a fixed perspective, reducing awareness of the surrounding environment. This project addresses that challenge by developing a head-tracking camera system that translates natural head movement into real-time
camera | motion. | The | design | integrates | wireless
communication, embedded control, servo motors, and a custom PCB to create a compact prototype that improves remote vision and operator control. By making camera movement more natural and intuitive, this system offers a practical step toward better remote sensing solutions for first responders in emergencies.

# Design and Development of a Head-Tracking FPV Camera Control Board

## Team Members: Karla McKenzie, Jacob Shillingburg, Martins Ugoh Advisor: Dr. Namuduri

# UNT Department of Electrical Engineering Denton Texas

# Introduction

# PCB Design

# Methods

Abstract | Results


References Electrical Design: •Boards use an external power supply (Transmitter:
18650 3000mAh battery cell; Receiver: 3.7V LiPo
Battery 500mAh;)
•On board linear regulator for 3.3V (AMS1117-3.3) •Integrated filtering capacitors to improve antenna signal stability
•Processed head movement into control signals using MPU6050
•Wireless communication to send tracking data using NRF24L01 & E01-ML01DP5
•Utilized control signals for pan and tilt servos motion •Designed an Arduino Pro Mini Carrier PCB in Altium Mechanical Design:
•Designed and Printed 3D parts (Drone, Case, Gimbal) •Assembled the camera and gimbal structure

# Acknowledgements

# Conclusion

Figure 1. PCB Schematic in Altium | Figure 2. PCB Layout in Altium
Features:
2 layers
GND and 5V planes
Dimensions: 57mm*35mm

# 3D Design

# Testing

Figure 3. 3D CAD Design for our Drone in Fusion360

Figure 4. Printed 3D Design of Transmitter Case

Figure 5. Printed 3D Design of Gimbal


Figure 6. Testing Downward View | Figure 7. Testing Top Right View | Figure 8. System Output (Transmitter)

We would like to thank the College of Engineering at the University of North Texas for funding. We also thank Dr. Namuduri and the Autonomous Systems Laboratory for their mentorship throughout this project. In addition, we appreciate the Department of Electrical Engineering for guidance and providing access to equipment and materials.

The developed head-tracking FPV camera system successfully demonstrated real-time camera movement based on user head motion. The project showed effective integration of electrical and mechanical design while improving remote viewing and operator awareness. This prototype provides a foundation for future use in drone and first responder applications.

The final prototype successfully demonstrated real-time head-tracking camera control, showing that the overall system functioned as intended. Ground testing confirmed wireless communication over distances up to 1 km under testing conditions. During assembly and testing, the PCB supported system integration; however, the pin headers were prone to stripping, which created a reliability issue during repeated connections and adjustments. Although flight testing was not completed, the prototype verified the core functionality of the design and identified an area for future hardware improvement.

# Future Work

- Redesign connection points to reduce stripping issues
- Perform full flight testing
- Test Mechanical stability under drone movement
- Refine tracking response for smoother camera motion
- Update the PCB for improved durability (weather)
- Evaluate performance in field conditions
- Explore greater communication range and system upgrades

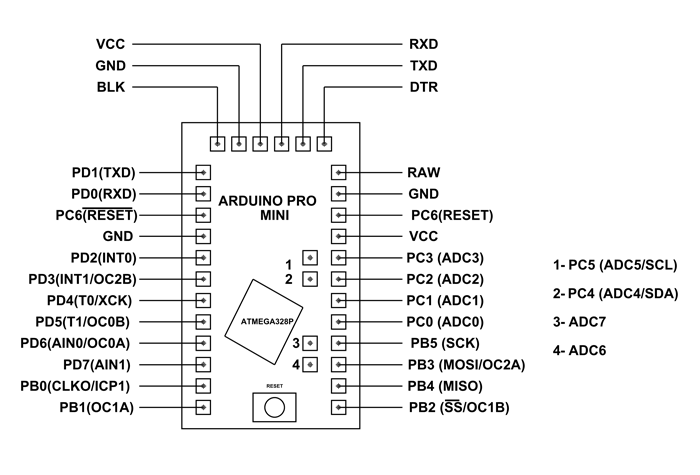
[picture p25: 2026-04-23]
Pin Diagrams/Arduino-Pro-Mini-Pin-Diagram.png

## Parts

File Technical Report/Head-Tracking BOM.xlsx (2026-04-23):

Item | Component name | Description | Quantity | Digikey #, or Mouser #, or link | Cost | Other sources of funding
1 | Arduino Pro Mini |  | 1 | https://www.amazon.com/HiLetgo-Atmega328P-Replace- | 13.99 | 100 - donor Nick Strife
2 | Accelerometer/Gyroscope Sensor |  | 1 | https://www.amazon.com/EC-Buying-Accelerometer-Gyroscope-Module16-Bit/dp/B0B3D6D1KD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 | 9.59 | 50 - donor ASME
3 | Power Supply Module |  | 1 | https://www.amazon.com/ALAMSCN-Converter-Lithium-Charging-Protection/dp/B08L6FYFNP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 | 8.59 | 150 - 50x3 UNT
4 | LDO Regulators |  | 1 | https://www.amazon.com/Chanzon-AMS1117-Including-Regulator-Transistor/dp/B083TDQBPN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 | 8.99 | components - Dr.Namuduri
5 | 1206 LEDs |  | 1 | https://www.amazon.com/AEDIKO-Lighting-Electronics-Components-Emitting/dp/B09XB7KSVZ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 | 4.99
6 | 1206 Resistors | 1/8W 1% | 1 | https://www.amazon.com/AEDIKO-Resistors-Capacitor-Resistor-Assortment/dp/B0BB113PJC?s=industrial | 7.99 | Pending- benefit nights on Fry
7 | 1206 Capacitors |  | 1 | https://www.amazon.com/1206-Capacitor-Kits-16values-Multilayer/dp/B0F5Q8V6BH | 6.99 | Pending- dropping off sponsor packets at businesses in denton
8 | Pin Header |  | 1 | https://www.amazon.com/dp/B08DVGCTKT?sp_csd=d2lkZ2V0TmFtZT1zcF9kZXRhaWw | 6.99
9 | Plug Connector |  | 1 | https://www.amazon.com/eBoot-Connector-Female-Cable-Battery/dp/B01M5AHF0Z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 | 7.19 | Total funding at the moment of request
10 | Transmitter Battery | 3.7V Lipo Battery 500mAh | 1 | https://www.amazon.com/EEMB-Battery-Rechargeable-Connector-Certified/dp/B095W6742D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 | 8.18 | 300
11 | 30AWG Wire |  | 1 | https://www.amazon.com/Fermerry-Silicone-Colors-Flexible-Stranded/dp/B089D31ZX6?sp_csd=d2lkZ2V0TmFtZT1zcF9hdGY | 8.99
12 | WTO5 FPV Camera |  | 1 | https://www.amazon.com/Wolfwhoop-5-8GHz-Transmitter-Interface-Quadcopter/dp/B073J61SSQ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 | 25.99
13 | 360 servo motors |  | 1 | https://www.amazon.com/JIANNIU-SG90%EF%BC%8CMicro-Steering-Suitable-Helicopter/dp/B09J86CD22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 | 7.99
14 | Cell Holder |  | 1 | https://www.amazon.com/BestTong-Battery-Holder-Contacts-Storage/dp/B0721Y3NDQ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 | 8.99
15 | 18650 3000mAh Battery Cell |  | 1 | https://www.amazon.com/QOJH-RAFZCCF-Rechargeable-Flashlight-Headlamp/dp/B0CTD2V247 | 13.99
17 | 24 Gauge Wire (24 AWG |  | 1 | https://www.amazon.com/Gauge-Wire-AWG-Electrical-Extension/dp/B09T6KGZKB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 | 5.99
18 | M3 Threaded Inserts |  | 1 | https://www.amazon.com/Ktehloy-Threaded-Printing-Components-M3x4x5mm/dp/B0CLKCQ2SH?s=industrial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 | 8.98
19 | M3 Screws |  | 1 | https://www.amazon.com/gp/product/B0CNJW37NJ?linkId=e344d34da9b92f3e78276b93feff1e09&language=en_US | 8.99
20 | 3D Printing filament |  | 2 | https://www.amazon.com/ELEGOO-Filament-Dimensional-Accuracy-Cardboard/dp/B0C8HY16ZD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 | 18.69
21 | Monitor | FEELWORLD P6XL 6 inch | 1 | https://www.amazon.com/FEELWORLD-Aluminium-Touchscreen-Brightness-Lightweight/dp/B0DP2CPKX8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 | 199.99
22 | FDTI(Programmer) |  | 1 | https://www.amazon.com/WWZMDiB-FT232RL-Converter-Adapter-Breakout/dp/B0BJKCSZZW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 | 6.49
23 | Transmiter and Reciever |  | 1 | https://www.amazon.com/EC-Buying-E01-ML01DP5-Transmission-Transceiver/dp/B0CDH1JJZG | 14.99
24 | Walksnail Avatar HD Goggles L |  | 1 | https://caddxfpv.com/products/walksnail-avatar-hd-goggles-l | 199.99
25 | Walksnail Avatar FPV VRX With Moonlight Kit |  | 1 | https://caddxfpv.com/products/walksnail-avatar-fpv-with-moonlight-kit?variant=49558843523374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 | 349 | Request for funding from UNT: 3,165.55
26 | Travel to Utah for URC Comp. | flights for drone team | 3 | flight to Salt lake city utah | 0
27 |  | stay for drone team may 26th- may 31st | 3 | stay for team in hanksville utah | 0
28
29 |  |  |  |  | 962.55

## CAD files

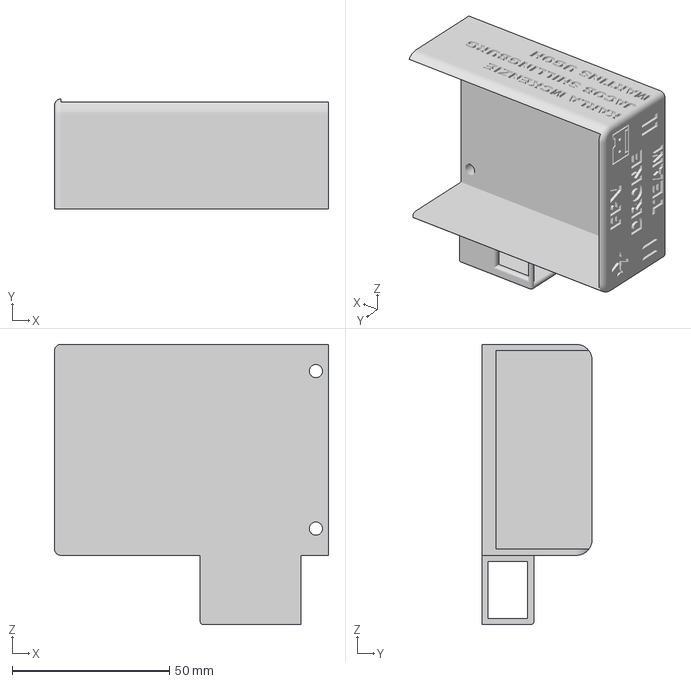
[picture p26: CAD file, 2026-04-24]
3D Models/FPV HEADSET MOUNT.3mf
87.0 x 35.0 x 89.0 mm

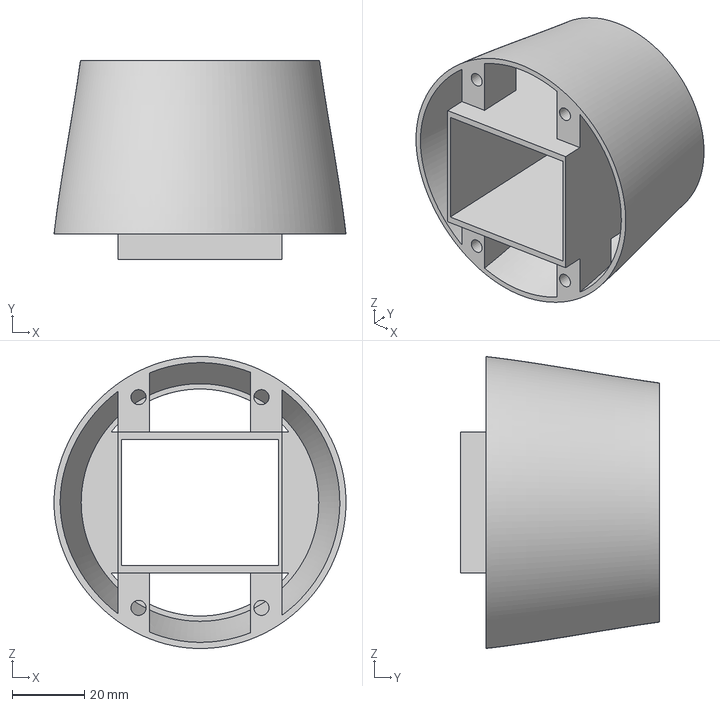
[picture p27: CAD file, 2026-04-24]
3D Models/new drone/MID FUSELAGE easy.3mf
80.9 x 55.0 x 80.9 mm

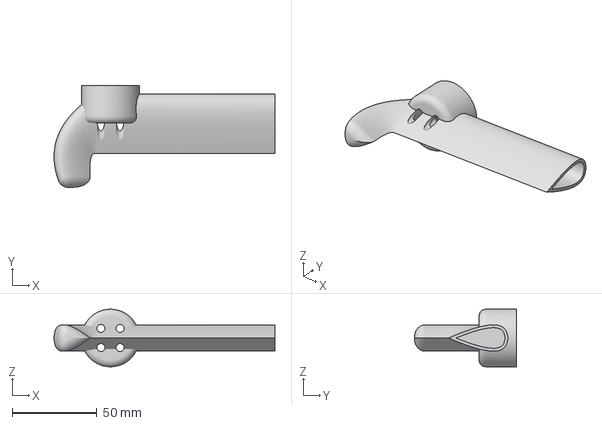
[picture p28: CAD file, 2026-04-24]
3D Models/new drone/WING done.3mf
130.4 x 60.0 x 34.0 mm

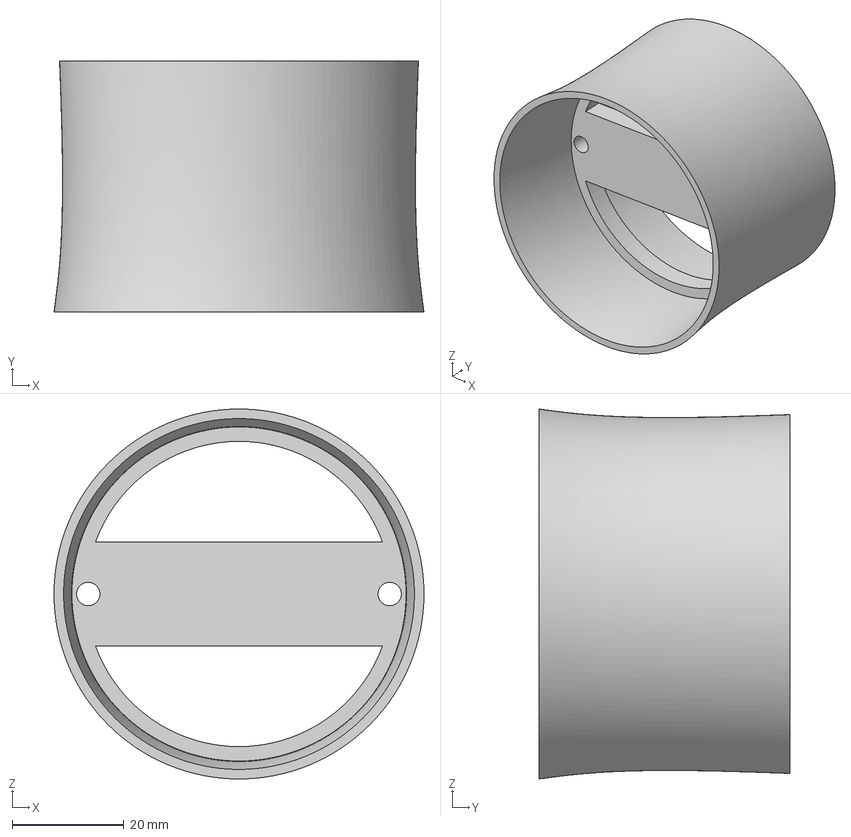
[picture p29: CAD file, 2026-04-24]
3D Models/new drone/Twist fuselage redone.3mf
66.3 x 45.0 x 66.3 mm

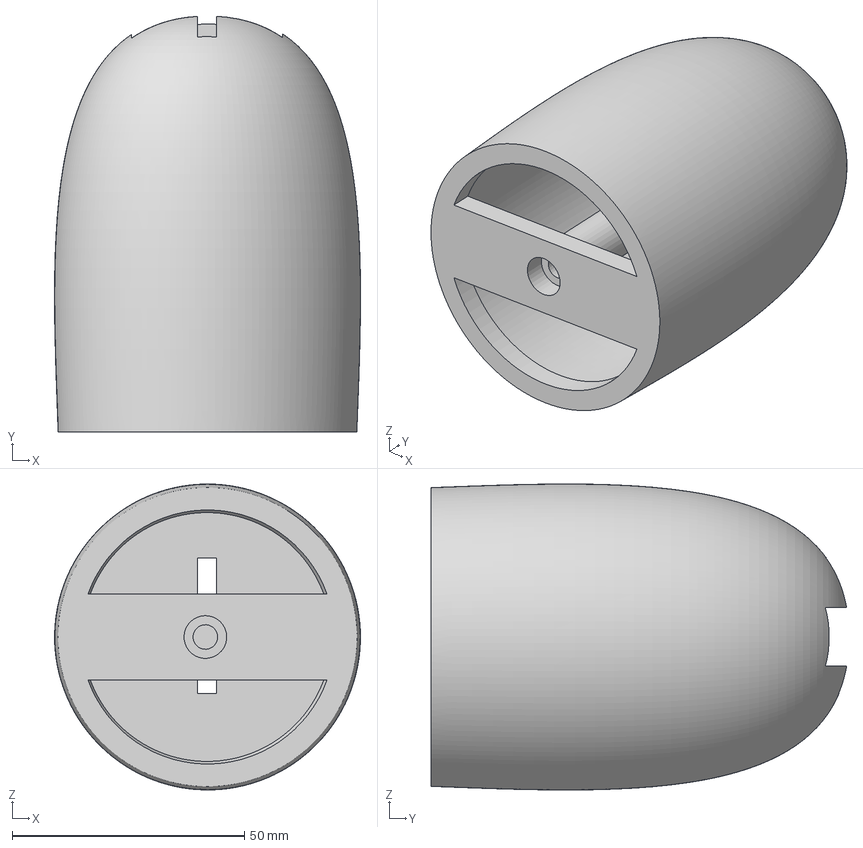
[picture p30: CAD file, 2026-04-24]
3D Models/new drone/TOP FUSELAGE light.3mf
65.9 x 89.4 x 65.9 mm

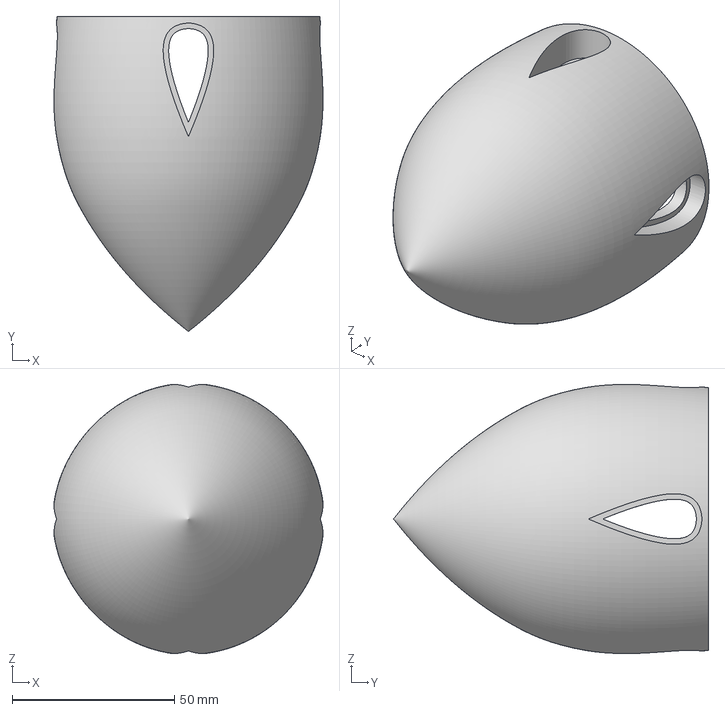
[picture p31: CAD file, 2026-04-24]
3D Models/new drone/BOTTOM FUSELAGE easy.3mf
82.8 x 97.0 x 82.9 mm

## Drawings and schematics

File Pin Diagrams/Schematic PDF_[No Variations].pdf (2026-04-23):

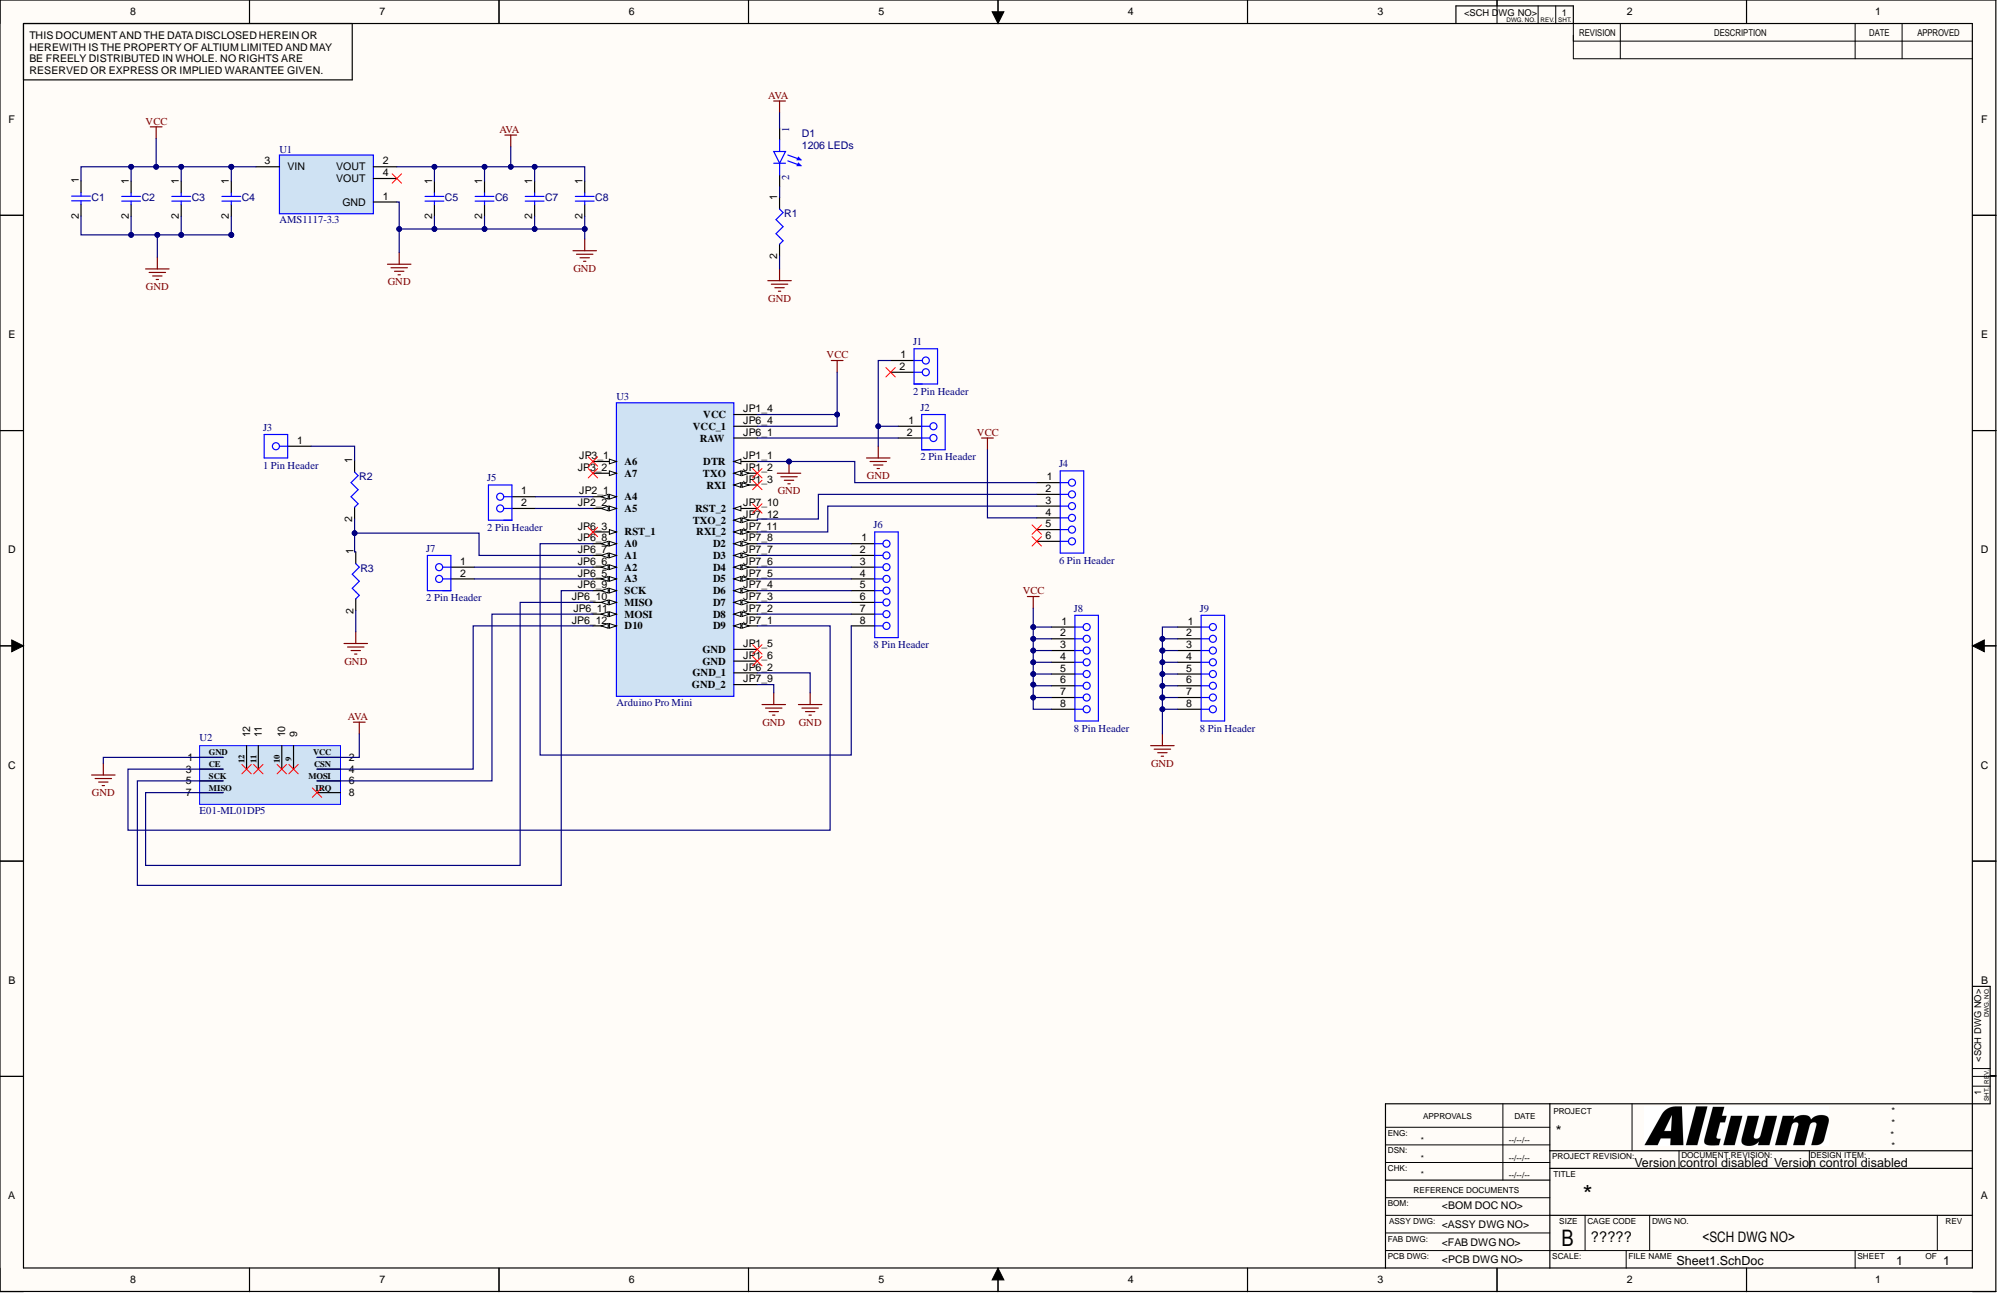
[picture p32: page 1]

<SCH DWG NO> | DWG. NO. | REV. | 1 SHT.

THIS DOCUMENT AND THE DATA DISCLOSED HEREIN OR HEREWITH IS THE PROPERTY OF ALTIUM LIMITED AND MAY BE FREELY DISTRIBUTED IN WHOLE. NO RIGHTS ARE RESERVED OR EXPRESS OR IMPLIED WARANTEE GIVEN. | AVA J1 | REVISION | DESCRIPTION | DATE | APPROVED

2 VCC

6 MOSI

REV. SHT. DWG. NO.

DATE | PROJECT * | * * APPROVALS * *

ENG: * | --/--/--

DSN: * | --/--/--

PROJECT REVISION: Version | DOCUMENT REVISION: control disabled Version control disabled | DESIGN ITEM:

CHK: * | --/--/--

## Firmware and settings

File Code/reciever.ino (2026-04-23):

#include <SPI.h>
#include <nRF24L01.h>
#include <RF24.h>
#include <Servo.h>

RF24 radio(9, 10);   // CE, CSN
const byte address[6] = "00001";

Servo pan;
Servo tilt;

struct DataPacket {
  int x;
  int y;
};

DataPacket data;

int panPos = 90;
int tiltPos = 90;

const int deadband = 2;   
const float alpha = 0.2; 

void setup() {
  Serial.begin(115200);
  delay(1000);

  Serial.println("RX boot");

  pan.attach(3);    // D3 = pan
  tilt.attach(5);   // D5 = tilt

  pan.write(panPos);
  tilt.write(tiltPos);

  if (!radio.begin()) {
    Serial.println("radio.begin failed");
    while (1);
  }

  radio.setAutoAck(false);
  radio.setPALevel(RF24_PA_MIN);
  radio.setDataRate(RF24_250KBPS);
  radio.setChannel(100);
  radio.openReadingPipe(0, address);
  radio.startListening();

  Serial.println("RX ready");
}

void loop() {
  if (radio.available()) {
    radio.read(&data, sizeof(data));

    data.x = constrain(data.x, 0, 180);
    data.y = constrain(data.y, 0, 180);

    if (abs(data.x - panPos) > deadband) {
      panPos = panPos + alpha * (data.x - panPos);
    }

    if (abs(data.y - tiltPos) > deadband) {
      tiltPos = tiltPos + alpha * (data.y - tiltPos);
    }

    pan.write(panPos);
    tilt.write(tiltPos);

    Serial.print("Pan: ");
    Serial.print(panPos);
    Serial.print("  Tilt: ");
    Serial.println(tiltPos);
  }

  delay(15);
}

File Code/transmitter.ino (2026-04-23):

#include <Wire.h>
#include <SPI.h>
#include <nRF24L01.h>
#include <RF24.h>

RF24 radio(9, 10);   // CE, CSN
const byte address[6] = "00001";

struct DataPacket {
  int x;
  int y;
};

DataPacket data;

const int MPU_ADDR = 0x68;

void setup() {
  Serial.begin(115200);
  delay(1000);

  Serial.println("TX boot");

  Wire.begin();

  Wire.beginTransmission(MPU_ADDR);
  Wire.write(0x6B);
  Wire.write(0);
  Wire.endTransmission(true);

  if (!radio.begin()) {
    Serial.println("radio.begin failed");
    while (1);
  }

  radio.setAutoAck(false);
  radio.setPALevel(RF24_PA_MIN);
  radio.setDataRate(RF24_250KBPS);
  radio.setChannel(100);
  radio.openWritingPipe(address);
  radio.stopListening();

  Serial.println("TX ready");
}

void loop() {
  int16_t AcX, AcY, AcZ, Tmp, GyX, GyY, GyZ;

  Wire.beginTransmission(MPU_ADDR);
  Wire.write(0x3B);
  Wire.endTransmission(false);
  Wire.requestFrom(MPU_ADDR, 14, true);

  AcX = Wire.read() << 8 | Wire.read();
  AcY = Wire.read() << 8 | Wire.read();
  AcZ = Wire.read() << 8 | Wire.read();
  Tmp = Wire.read() << 8 | Wire.read();
  GyX = Wire.read() << 8 | Wire.read();
  GyY = Wire.read() << 8 | Wire.read();
  GyZ = Wire.read() << 8 | Wire.read();

  data.x = map(AcX, -17000, 17000, 0, 180);
  data.y = map(AcY, -17000, 17000, 180, 0);   // inverted Y

  data.x = constrain(data.x, 0, 180);
  data.y = constrain(data.y, 0, 180);

  bool ok = radio.write(&data, sizeof(data));

  Serial.print("X: ");
  Serial.print(data.x);
  Serial.print("  Y: ");
  Serial.print(data.y);
  Serial.print("  | ");
  Serial.println(ok ? "SENT" : "FAILED");

  delay(50);
}
